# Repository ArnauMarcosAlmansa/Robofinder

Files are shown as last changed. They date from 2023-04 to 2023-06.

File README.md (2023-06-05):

<h1 style="font-size: 48px;">ROBOFINDER</h1>

# Introducción
<p align="justify">
Robofinder es un proyecto de la asignatura de Robótica del Grado en Ingeniería Informática de la Universidad Autónoma de Barcelona.
</p>

<p align="justify">
Este robot ha sido diseñado para la exploración y el mapeo de entornos. Gracias al algorismo de Simultaneous Localization and Mapping (SLAM), RoboFinder tiene la capacidad de generar mapas tridimensionales detallados mientras se mueve con autonomía. Robofinder es un robot móvil autónomo capaz de navegar por un edificio y poder encontrar todo tipo de objetos y localizarse a sí mismo a partir de estos.  Este es un proyecto basado en lo que se conoce como visual SLAM. 
</p>

<div align="center">
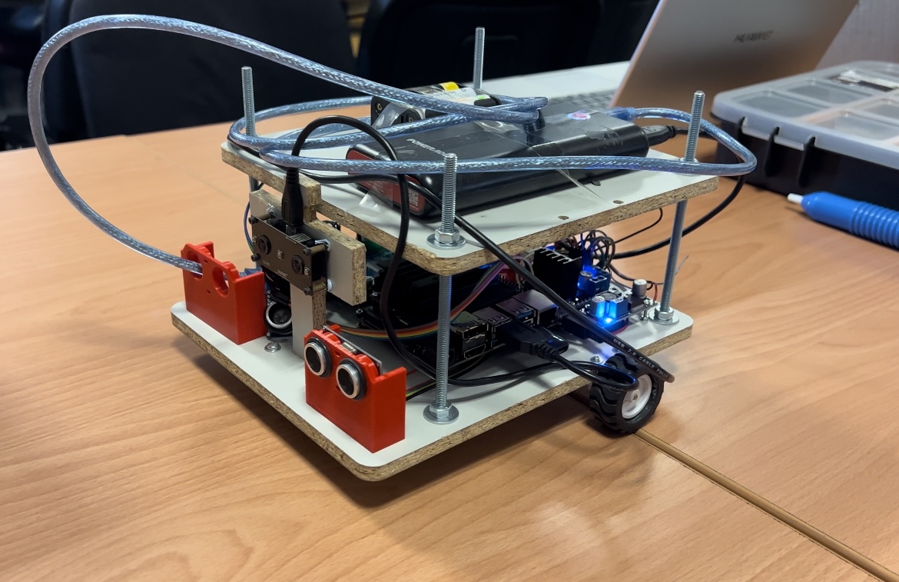
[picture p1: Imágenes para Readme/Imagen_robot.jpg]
Foto
    
</div>

# Tabla de Contenidos
- [Introducción](#introducción)
- [Características](#características)
- [Hardware](#hardware)
    - [Componentes](#componentes)
    - [Circuito](#circuito)
    - [Diseño y Materiales](#diseño-y-materiales)  
- [Software](#software)
- [Resultado Final](#resultado-final)
- [Demo Video](#demo-video)
- [Agradecimientos](#agradecimientos)
- [Autores](#autores)

# Características

<p align="justify">
Su sistema se basa en una cámara estéreo y encoders, permitiéndole obtener una comprensión precisa de su ubicación en todo momento.
</p>

<p align="justify">
RoboFinder cuenta con un potente sistema de control. Una Jetson Nano se encarga del procesamiento, mientras que la comunicación I2C asegura una transmisión de información fluida y confiable entre los componentes. Este enfoque de control inteligente garantiza movimientos precisos y coordinados en cada acción que realiza.
</p>

<p align="justify">
Además de su capacidad de mapeo y navegación, RoboFinder se preocupa por la seguridad. Sus sensores de ultrasonido le permiten detectar obstáculos cercanos y detenerse de manera segura para evitar colisiones. Para brindar una experiencia visualmente atractiva, hemos incorporado LEDs que indican el movimiento del robot, añadiendo un toque estético a su funcionalidad.
</p>

<p align="justify">
Representa un avance significativo en la exploración robótica, abriendo nuevas posibilidades en campos como la cartografía, la inspección de entornos complejos y la investigación científica. Su combinación de tecnología innovadora y capacidad de adaptación lo convierten en una herramienta versátil y confiable.
</p>

<p align="justify">
Descubre con RoboFinder un mundo de posibilidades en la exploración y mapeo de entornos. Siéntete parte de la revolución robótica y únete a nosotros en la búsqueda de soluciones avanzadas para desafíos del mundo real
</p>

# Hardware
## Componentes
Principales componentes utilizados:

 Componente                                  |        Componente                                   |              
|:--------------------------------------------:|:--------------------------------------------:|
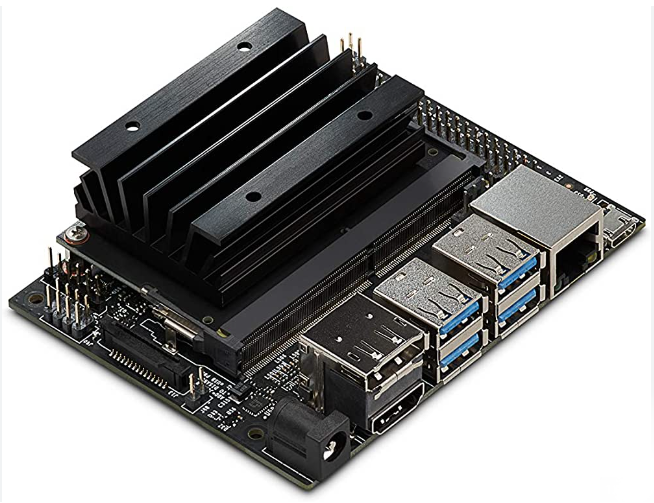
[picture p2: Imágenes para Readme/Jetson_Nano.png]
Jetson Nano
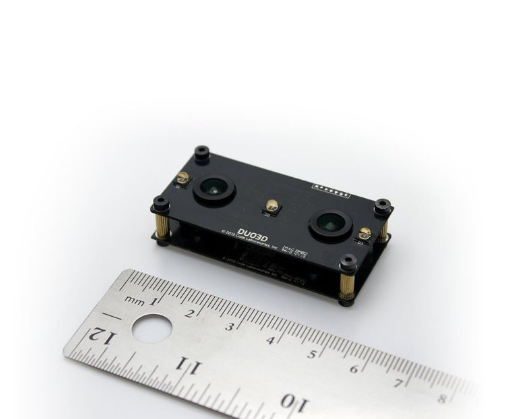
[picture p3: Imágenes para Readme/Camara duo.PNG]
DUO MLX - USB Stereo Camera
| **Nvidia Jetson Nano Developer Kit**  | **DUO MLX - USB Stereo Camera**  |
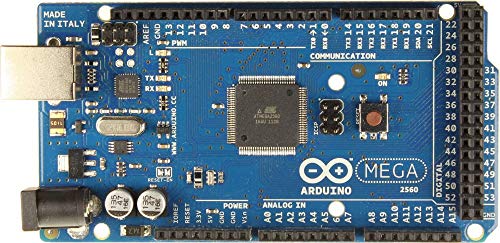
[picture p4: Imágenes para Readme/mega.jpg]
1 Arduino Mega
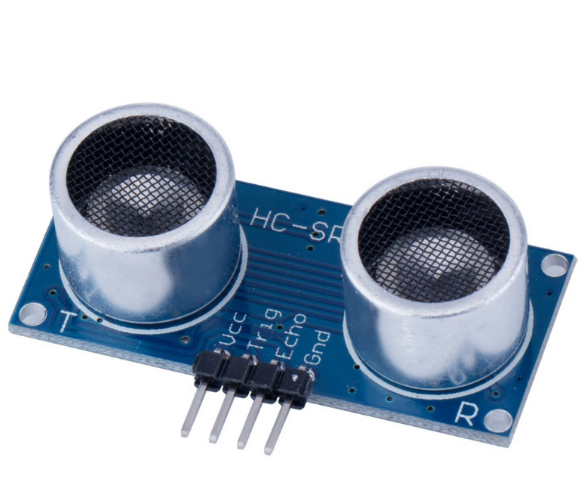
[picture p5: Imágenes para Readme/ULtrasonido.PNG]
2 Sensores de distancia por ultrasonidos HC-SR04
| **1 Arduino Mega**    | **2 Sensores de distancia por ultrasonidos HC-SR04**  |
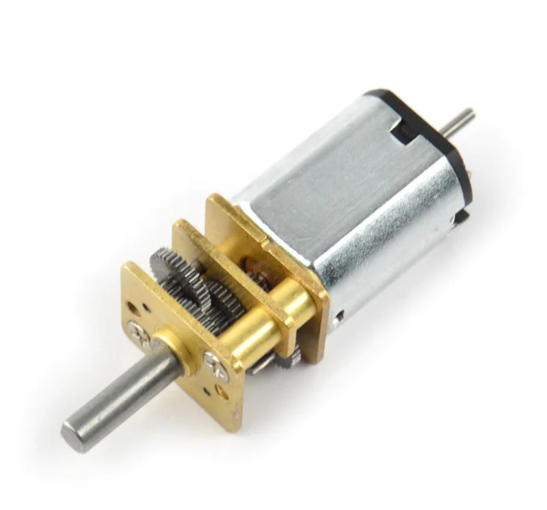
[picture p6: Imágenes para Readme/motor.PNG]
2 Motor Micro Metal 150:1
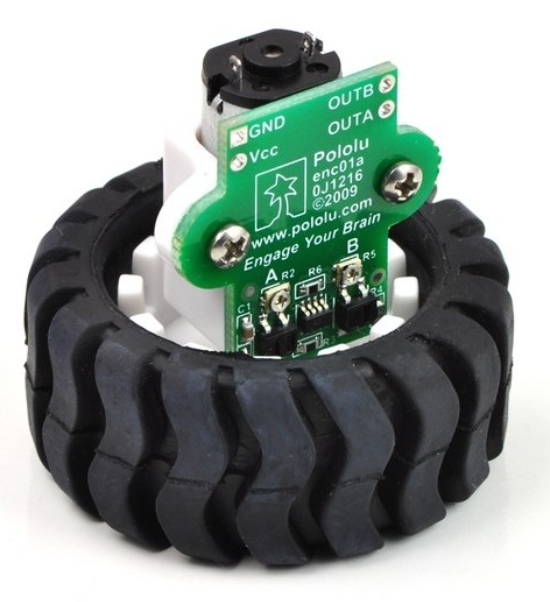
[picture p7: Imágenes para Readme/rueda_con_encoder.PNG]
2 Ruedas antideslizantes con encoders
| **2 Motor	Micro Metal 150:1**  | **2 Ruedas antideslizantes con encoders**                         |
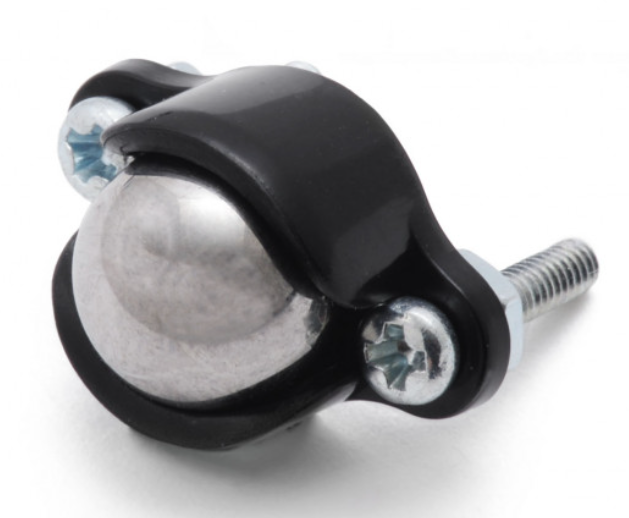
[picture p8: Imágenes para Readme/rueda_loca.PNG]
Rueda loca
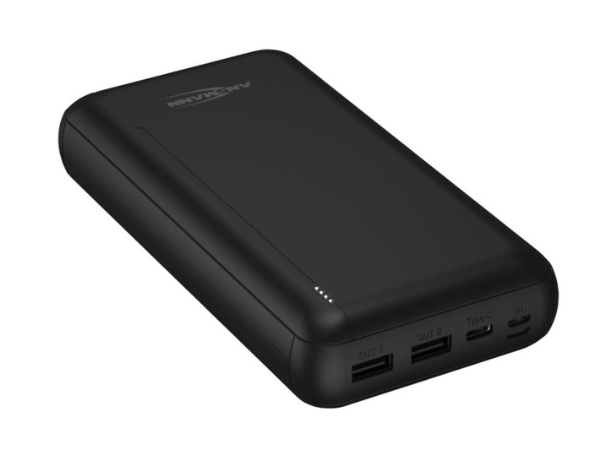
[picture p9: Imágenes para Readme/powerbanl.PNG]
Power Bank 20A
| **1 Rueda Loca Metálica** | **Power Bank 20A** |

## Circuito
Esquema global de Robofinder:

<div align="center">
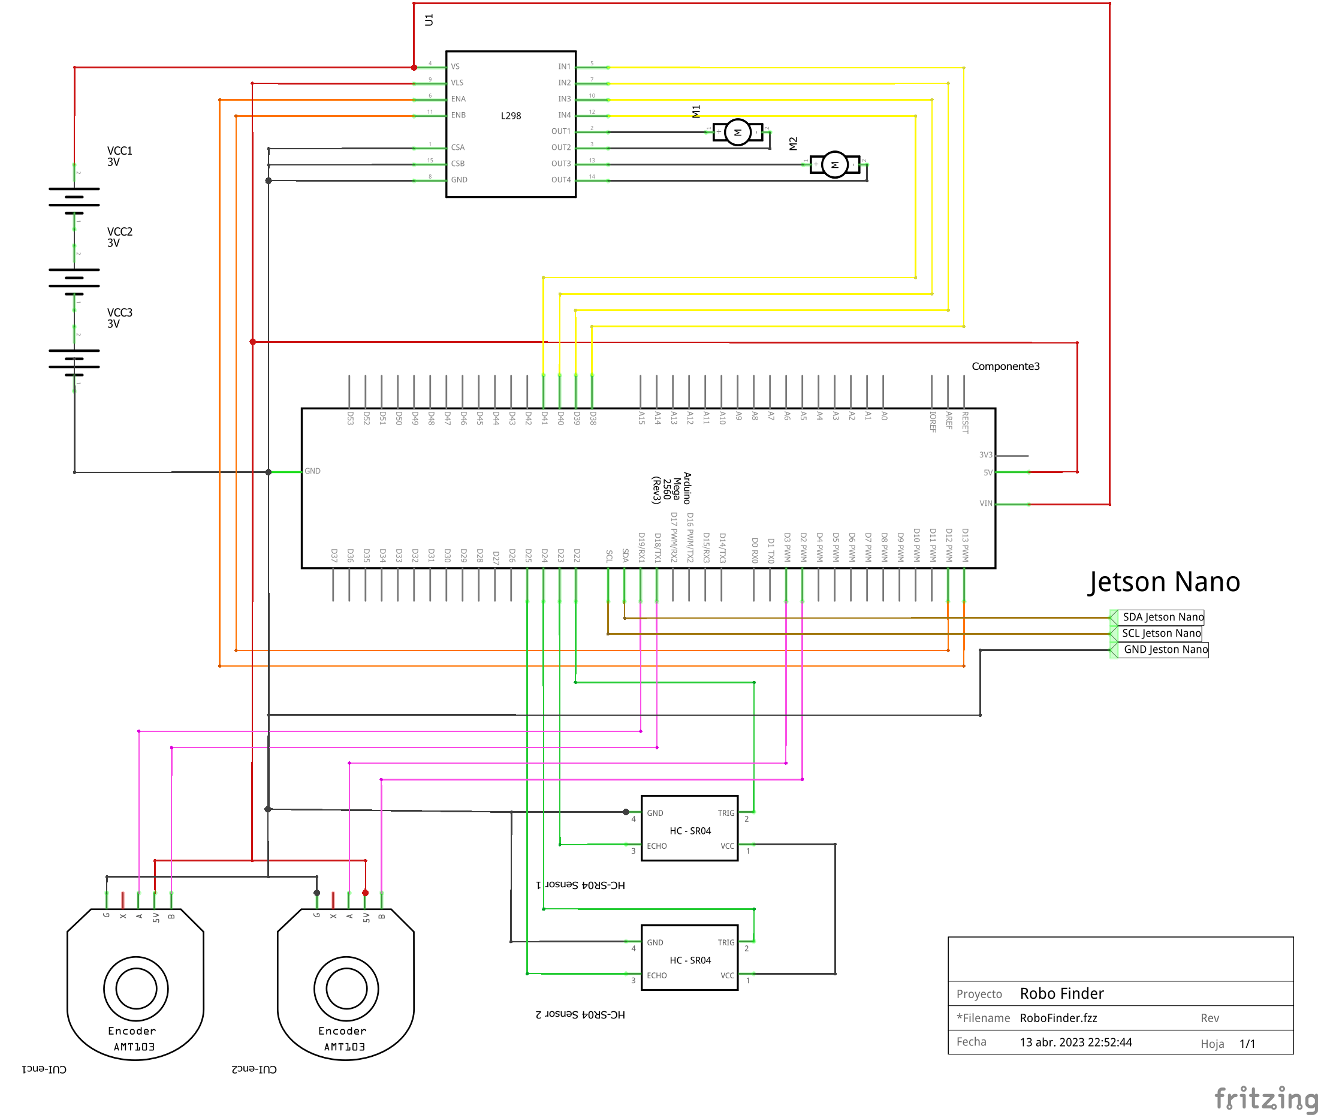
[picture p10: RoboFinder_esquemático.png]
Circuito
    
</div>

<p align="justify">
El Arduino tiene conectado el controlador de motores (L298N), los dos sensores de ultrasonido (HC-R04) y los encoders para detectar el movimiento de los motores.
Aparte el Arduino se comunica con la Jetson Nano mediante I2C. 
En la Jetson Nano tenemos conectada la cámara estéreo (DUO 3D MLX) mediante USB y la conexión de I2C mediante GPIO (puerto 3 SDA , puerto 5 SCL y puerto 6 GND).
</p>

# Diseño y Materiales
Diseño final de la estructura:

 Componente                                  |        Componente                                   |              
|:--------------------------------------------:|:--------------------------------------------:|
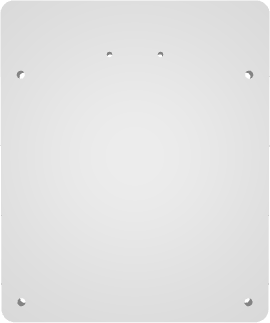
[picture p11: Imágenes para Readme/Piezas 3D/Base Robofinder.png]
Base del Robot
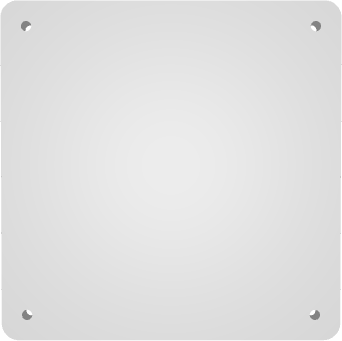
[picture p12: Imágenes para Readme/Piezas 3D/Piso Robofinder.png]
Piso intermedio y superior del Robot
| **Base del Robot**  | **Piso intermedio y superior del Robot** 
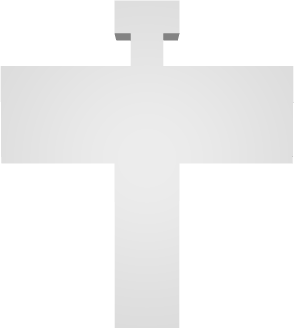
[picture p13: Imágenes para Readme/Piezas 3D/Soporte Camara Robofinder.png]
Soporte de la cámara 3D
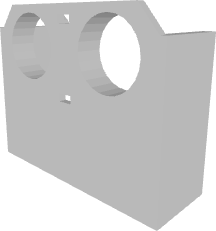
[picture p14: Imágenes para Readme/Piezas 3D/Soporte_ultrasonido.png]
Soporte para los sensores de ultrasonido
| **Soporte de la cámara 3D**  | **Soporte para los sensores de ultrasonido** 
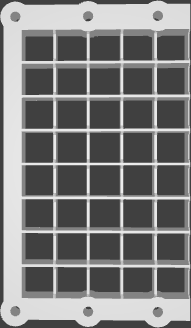
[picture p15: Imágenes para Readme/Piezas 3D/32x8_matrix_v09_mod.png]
Soporte para la matriz led
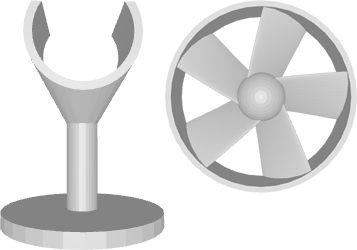
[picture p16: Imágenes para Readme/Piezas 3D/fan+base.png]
Soporte para el motor y aspa
| **Soporte para la matriz led**  | **Soporte para el motor y aspa** 

Si quieres ver el diseño en 3D en detalle, presiona en esta imagen:

<div align="center">
<a href="https://github.com/ArnauMarcosAlmansa/Robofinder/blob/master/models/Piezas_robofinder_montado.stl">
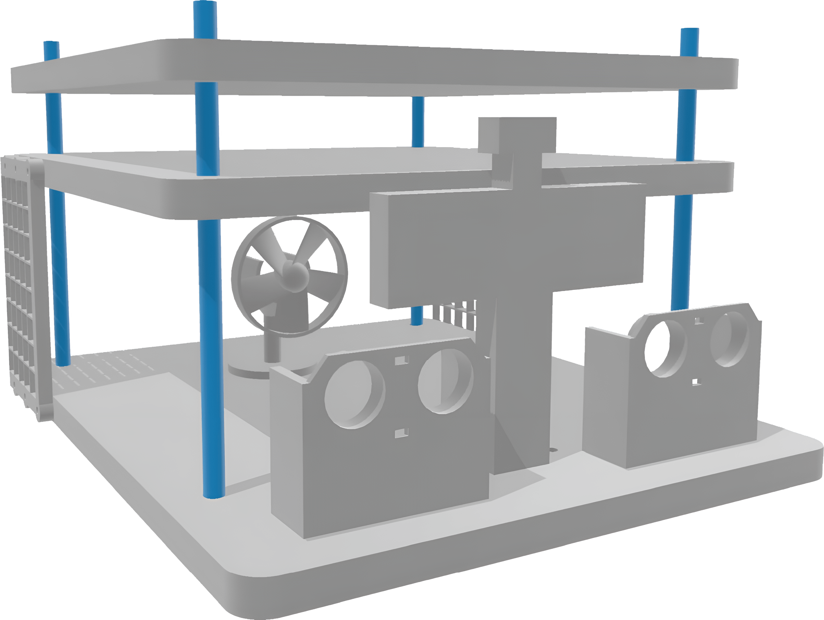
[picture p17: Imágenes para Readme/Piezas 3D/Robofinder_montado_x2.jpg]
  
</a>
</div>

# Software
## Diagrama Software:

<div align="center">
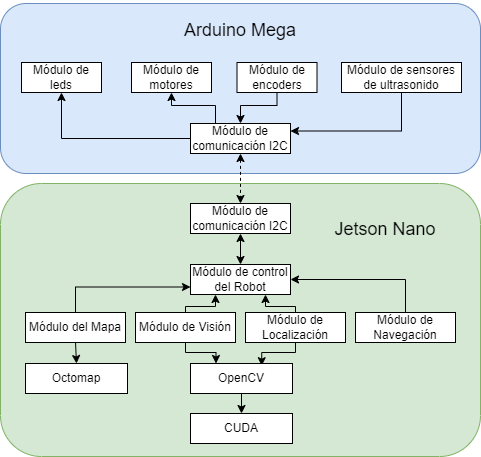
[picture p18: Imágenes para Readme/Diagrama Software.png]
Diagrama Software
    
</div>

## Módulos para el Arduino:

<div align="justify">
    
- **Módulo de control de motores:** Encargado de comandar a los motores: cómo tienen que moverse, velocidad, sentido; y qué motor debe moverse para poder moverse en línea recta o hacer curvas sobre su propio eje o abiertas; también poder frenar por si detecta algún imprevisto.

- **Módulo de sensores encoder:** Para poder leer datos de los encoders, cuantas vueltas dan las ruedas, o cuando completan una vuelta, etc.

- **Módulo de sensores de ultrasonido:** Para poder obtener los valores de los sensores de ultrasonido y poder alertar sobre objetos en la trayectoria.

- **Módulo de comunicación I2C:** Para poder comunicarse con la Jetson Nano. Tanto para recibir como enviar información, respecto a cuando hay que empezar a moverse (sentido, velocidad, posición final) o si hay que pararse. Permite comunicar los sensores de ultrasonido y los encoders con la Jetson para que así esta pueda tener los valores de estos sensores.

- **Módulo de control (interpretar órdenes que da la Jetson, capacidad de responder a imprevistos):** Entender las órdenes que recibimos de la Jeston Nano y poder gestionar las interrupciones que nos pueden dar los sensores de ultrasonido si un objeto inesperado se nos cruza en nuestra trayectoria.

- **Módulo de leds:** Permite definir distintos patrones en la matriz led que tiene el robot. Esta nos notifica cuando el robot se mueve, hacia qué dirección lo hace o si está parado.
    
</div>

## Módulos para la Jetson:

<div align="justify">

- **Módulo de comunicación I2C** Para poder comunicar con el Arduino cuando ha de empezar a mover los motores, qué motores, a que velocidad, también para recibir datos de los sensores de ultrasonido y los valores de los encoders. La comunicación se hace usando un protocolo de mensajes que hemos definido nosotros. Este protocolo envia un byte indicando el tipo de mensaje y un payload de datos.

- **Módulo de Mapa**
Generar un mapa de ocupación 3D del espacio donde se mueve el robot para poder navegar y consultar que tiene el robot a su alrededor y no colisionar con los objetos. Esto nos permite intentar localizar el robot y navegar teniendo en cuenta parte del entorno que el robot no está viendo en un momento concreto.
Hemos hecho uso de la librería OctoMap (https://github.com/OctoMap/octomap).

- **Módulo de Visión**
Este módulo es el encargado de hacer las imágenes con la cámara estéreo. 
Aplicamos el detector de características ORB para encontrar puntos de interés junto con BruteForce Matcher. Hacemos la correspondencia entre los puntos de ambas imágenes y filtramos las correspondencias para quitar las malas. Esto lo hacemos con el ratio de Lowe y filtrando las que tienen coordenada ‘y’ muy diferente. 
Triangulamos los puntos en el espacio 3D de la cámara. Luego los convertimos al espacio 3D del mundo.
Para hacer el procesamiento usamos OpenCV con CUDA.

- **Módulo de Localización**
Este módulo se encarga de intentar ubicar al robot dentro del espacio usando la información del mapa y los puntos que detecta la cámara.
Para conseguir ubicar el robot este módulo incorpora la localización de Monte Carlo para poder determinar en que zona está el robot. 
Concretamente, generamos partículas en un rango probable de error del robot. Para asignar a cada partícula un peso hacemos RayCast desde la posición y orientación de una especie de cámara virtual de cada partícula y hacemos un KNN con k = 1 con los puntos detectados de la cámara, asignando un peso menor a aquellas partículas que tienen menor correspondencia con los puntos de la cámara.
Después de esto, hacemos un resampling de partículas con el algoritmo llamado Random Wheel, que consiste en  generar nuevas partidas a partir del peso cumulativo de las anteriores.
Todo el proceso anterior se itera cinco veces para refinar y aproximar la posición estimada del robot.
Para este módulo utilizamos la parte de ML de OpenCV.

- **Módulo de Navegación**
Este módulo se encarga de planificar la navegación local.
Este módulo es el que se encarga de generar las órdenes que finalmente llegan al Arduino para la gestión de los motores y de los sensores. 
Teniendo en cuenta la posición del robot, hacemos raycast 360 grados alrededor del robot a 15 alturas diferentes de 0.5 cm a 15.5 cm, que es la altura del robot. A partir de los datos del raycast, el robot busca un ángulo donde no haya obstáculos, mira que no haya obstáculos con los ultrasonidos y avanza.

</div>

# Resultado Final

# Demo Video
Presiona la miniatura para visualizar el video en youtube de todo el proceso!

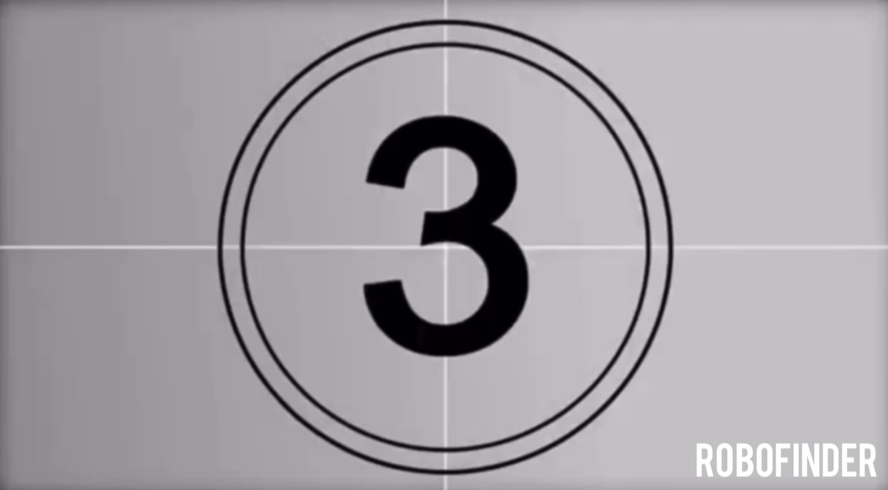
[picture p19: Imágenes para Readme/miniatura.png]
Demo del proyecto (https://youtu.be/TqlxrmKnXCs/)


# Agradecimientos
<p align="justify">
Queremos destacar y agradecer especialmente a la UAB, junto a los profesores de esta asignatura por proporcionarnos los mejores componentes posibles y por el apoyo brindado semanalmente.
</p>

[Universitat Autònoma de Barcelona (UAB)](https://www.uab.cat/web/universitat-autonoma-de-barcelona-1345467954409.html)

<p align="justify">
También al equipo del Open lab por facilitarnos la impresión 3D, el material y todas las herramientas que nos han permitido llevar a cabo nuestro robot.
</p>

[Open Labs UAB](https://www.uab.cat/open-labs/)

# Autores
- [Pere Pérez López](https://github.com/Pachi23)

- [Lluís Alonso Pichardo](https://github.com/lluisalosnsop)

- [Arnau Marcos Almansa](https://github.com/ArnauMarcosAlmansa)

- [Sergi Sanz Orellana](https://github.com/sergisanzorellana)

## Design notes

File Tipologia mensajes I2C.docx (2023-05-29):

# Arduino:

Tiene:

- Controladora de Motores
- Encoders
- Sensor ultrasonido

Recibe:

- Órdenes controladora de motores

Envía:

- Medida sensores ultrasonido
- Datos Enconders.

Con 2Bytes para los mensajes.

0 - 255 | 0 - 255
Canal | Valor

## Canales

### Motores:

10 -> Enable Motors (Sin mensaje 0Bytes)

11 -> Forward (Velocidad motor L (1Byte), Velocidad motor R (1Byte), Valor final encoder (2Bytes))

12 -> Backward (Velocidad motor L (1Byte), Velocidad motor R (1Byte), Valor final encoder (2Bytes))

13 -> Left (Velocidad motor L (1Byte), Velocidad motor R (1Byte), Valor final encoder (2Bytes))

14 -> Right (Velocidad motor L (1Byte), Velocidad motor R (1Byte), Valor final encoder (2Bytes))

15 -> Stop (Sin mensaje 0Bytes)

### Encoder:

20 -> Encoder Left (Sin mensaje 0Bytes)

21 -> Encoder Right (Sin mensaje 0Bytes)

22-> Reset Encoder Left (Sin mensaje 0Bytes)

23-> Reset Encoder Right (Sin mensaje 0Bytes)

### Ultrasound:

31 -> Ultrasound Left (Sin mensaje 0Bytes)

32 -> Ultrasound Right (Sin mensaje 0Bytes)

### LED:

40 -> Led Off (Sin mensaje 0Bytes)

Canales primera propuesta:

Controladora Motor Izquierda.

Característica | Canal | Rango de Valor
Velocidad | 10 | 1-255
Sentido | 11 | 1 -> Forward; 2 -> Backward.
Stop | 12 | 1
Aceleración | 13 | 1-255 (0 no tiene sentido)
Deceleración | 14 | 1-255 (0 no tiene sentido)

Controladora Motor derecha

Característica | Canal | Rango de Valor
Velocidad | 20 | 1-255
Sentido | 21 | 1 -> Forward; 2 -> Backward.
Stop | 22 | 1
Aceleración | 23 | 1-255 (0 no tiene sentido)
Deceleración | 24 | 1-255 (0 no tiene sentido)

Encoder Rueda Izquierda Petición | 30
Respuesta | 31

Encoder Rueda Derecha petición | 40
Respuesta | 41

Sensor Ultrasonido Izquierda | 50
Interrupción del sensor Izquierdo | 51

Sensor Ultrasonido Derecha | 60
Interrupción del sensor derecha | 61

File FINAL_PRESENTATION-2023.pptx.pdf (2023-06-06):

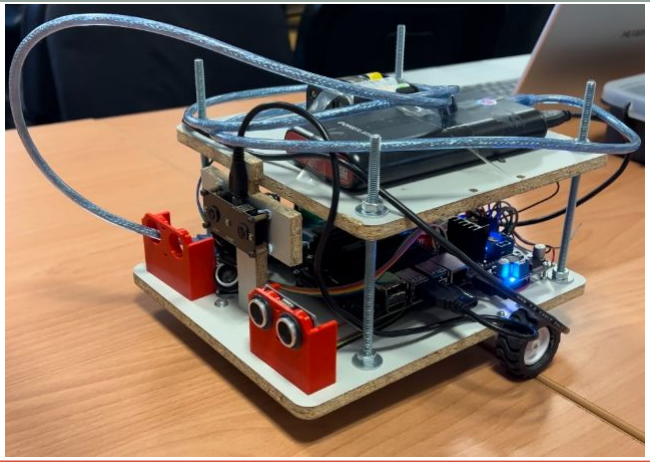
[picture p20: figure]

# ROBOFINDER

Arnau Marcos Almansa Pere Pérez López Lluís Alonso Pichardo | Robofinder es un robot móvil autónomo capaz de navegar por un edificio, detectar puntos en el entorno y localizarse a sí mismo a partir de estos. Este es un proyecto basado en lo que se conoce como visual SLAM.
| Sergi Sanz Orellana

ROBÒTICA, LLENGUATGE I PLANIFICACIÓ – ENGINYERIA INFORMÀTICA - UAB

# 1. Arquitectura hardware i software

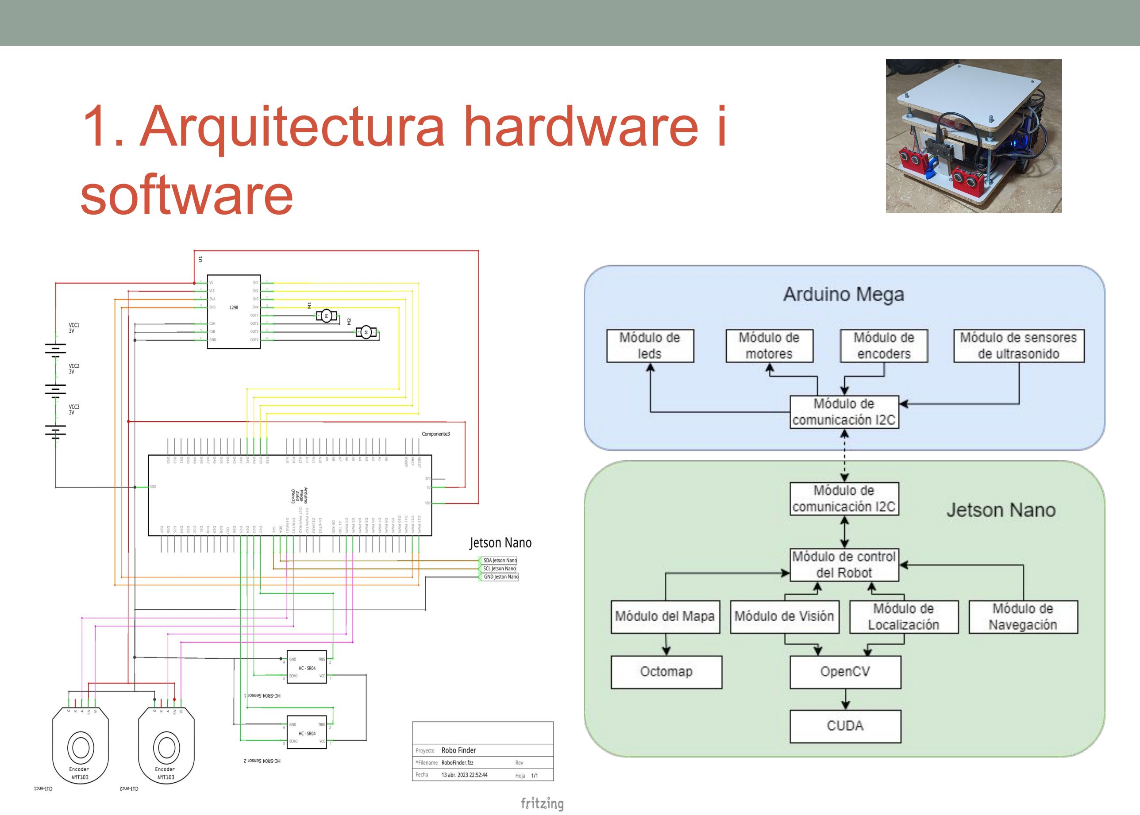
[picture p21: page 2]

# 2. Algorísmica

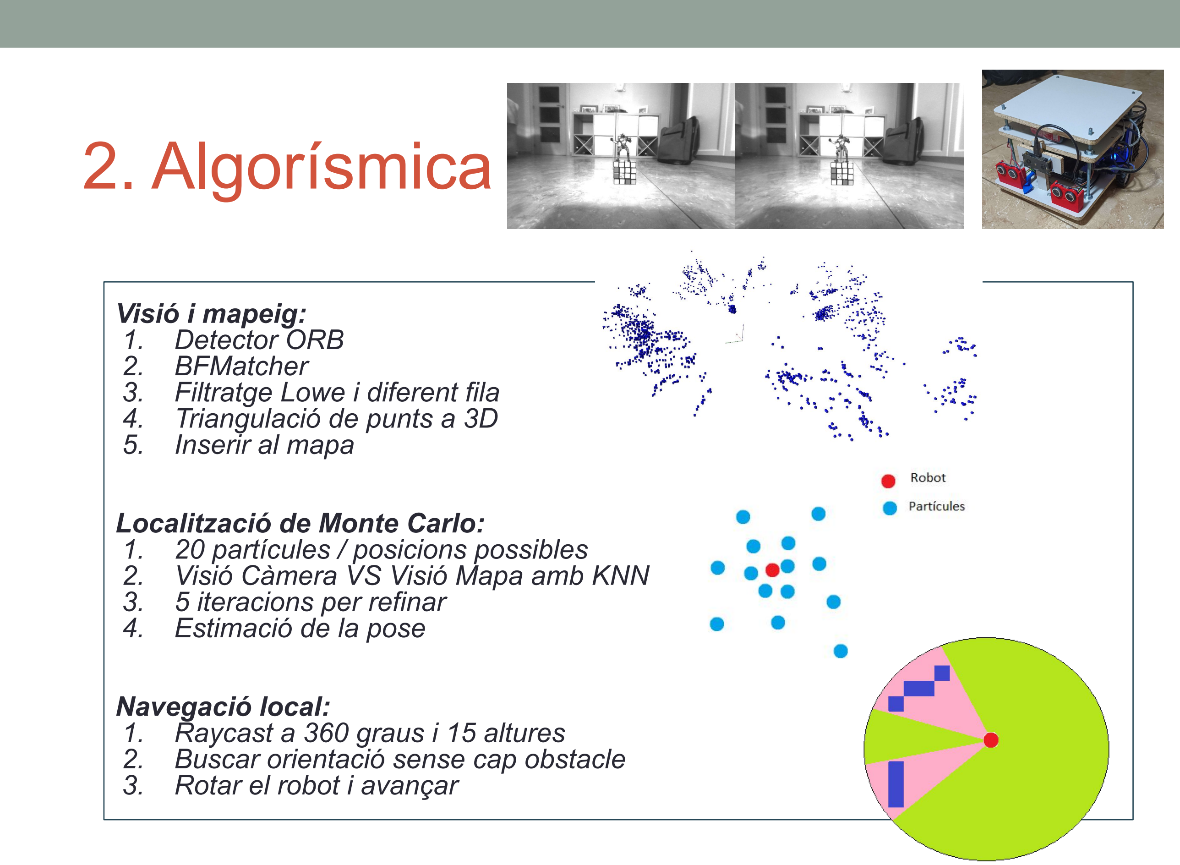
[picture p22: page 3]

Visió i mapeig:
1. Detector ORB
2. BFMatcher
3. Filtratge Lowe i diferent fila
4. Triangulació de punts a 3D
5. Inserir al mapa

Localització de Monte Carlo:
1. 20 partícules / posicions possibles
2. Visió Càmera VS Visió Mapa amb KNN
3. 5 iteracions per refinar
4. Estimació de la pose

Navegació local:
1. Raycast a 360 graus i 15 altures
2. Buscar orientació sense cap obstacle
3. Rotar el robot i avançar

# FOTOS, VIDEO i Git

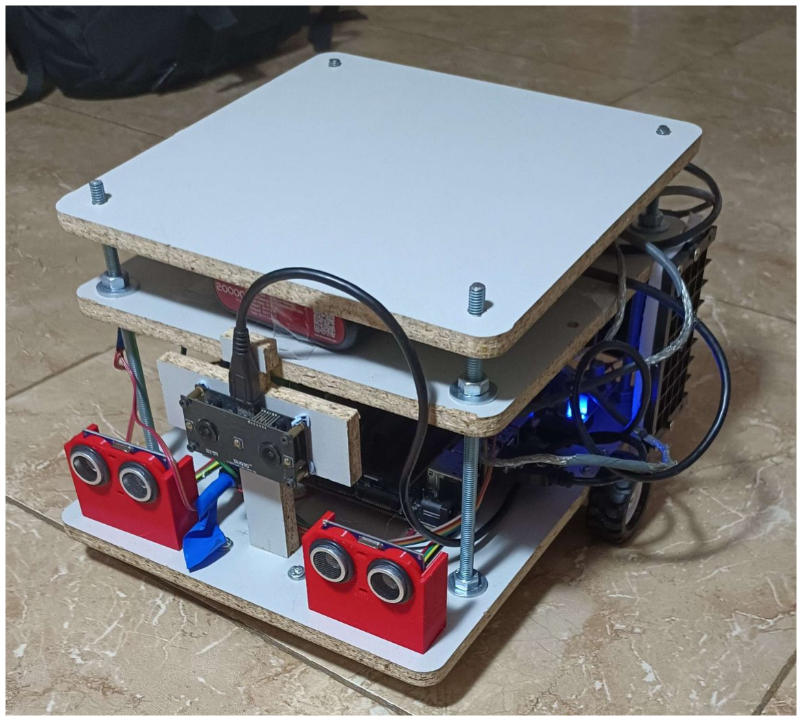
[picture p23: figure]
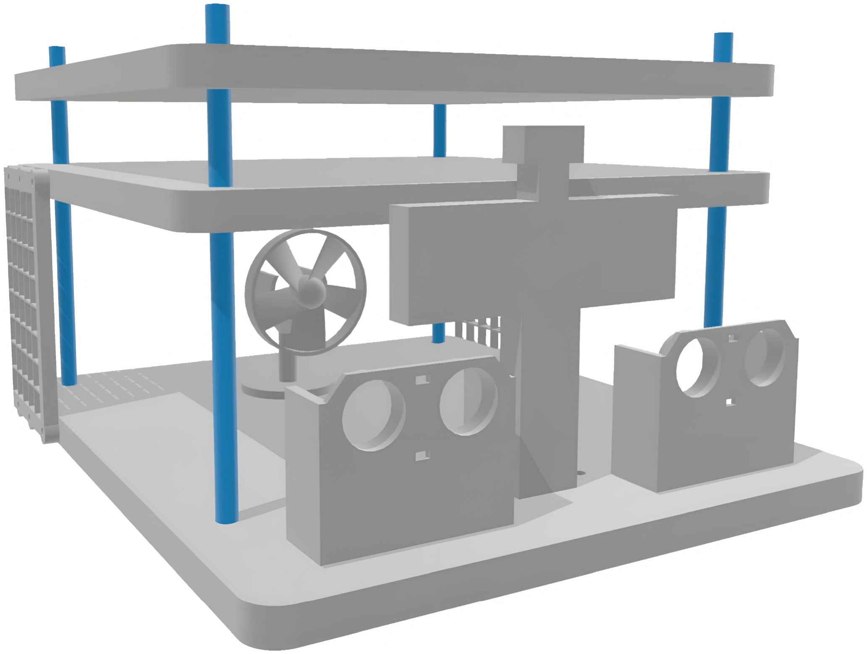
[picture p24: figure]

# https://youtu.be/TqlxrmKnXCs

https://github.com/ArnauMarcosAlmansa/Robofinder

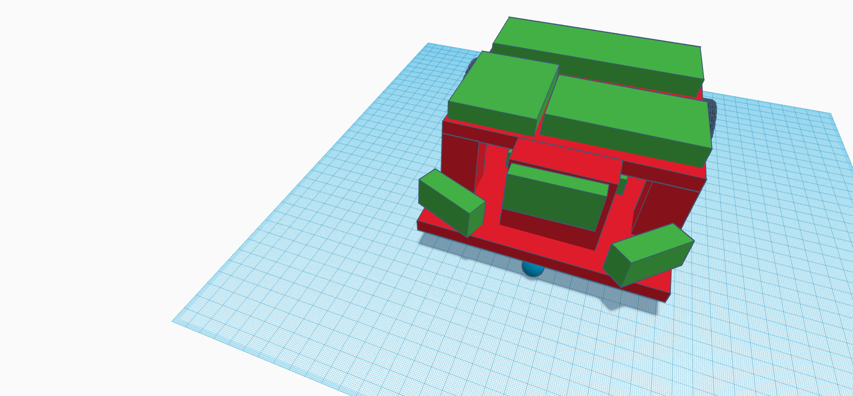
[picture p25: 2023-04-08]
ROBOT DESIGN.png

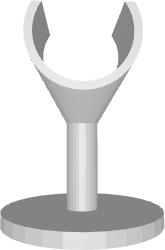
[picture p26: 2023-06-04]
Imágenes para Readme/Piezas 3D/fan_base.png

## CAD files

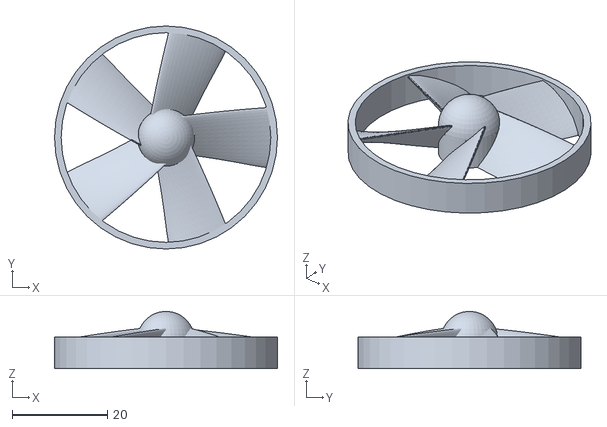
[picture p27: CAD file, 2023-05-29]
models/Fan/fan.stl
46.8 x 46.8 x 12.0

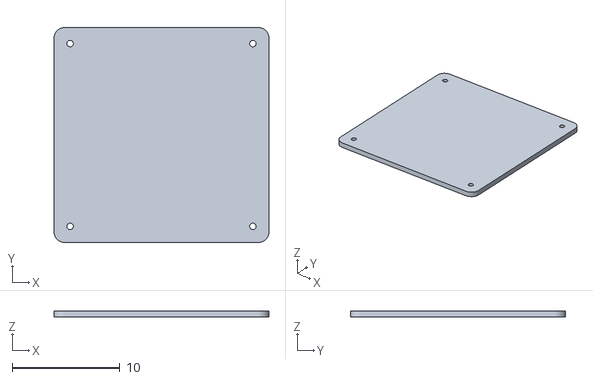
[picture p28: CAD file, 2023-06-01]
models/Fresadora/Piso Robofinder.stl
20.0 x 20.0 x 0.6

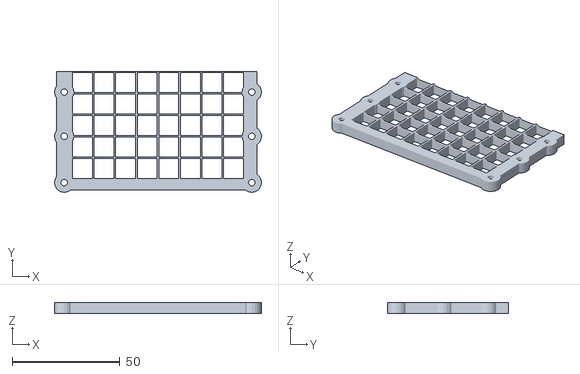
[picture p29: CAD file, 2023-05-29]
models/Matriz led/32x8_matrix_v09_mod.stl
96.0 x 56.0 x 5.00

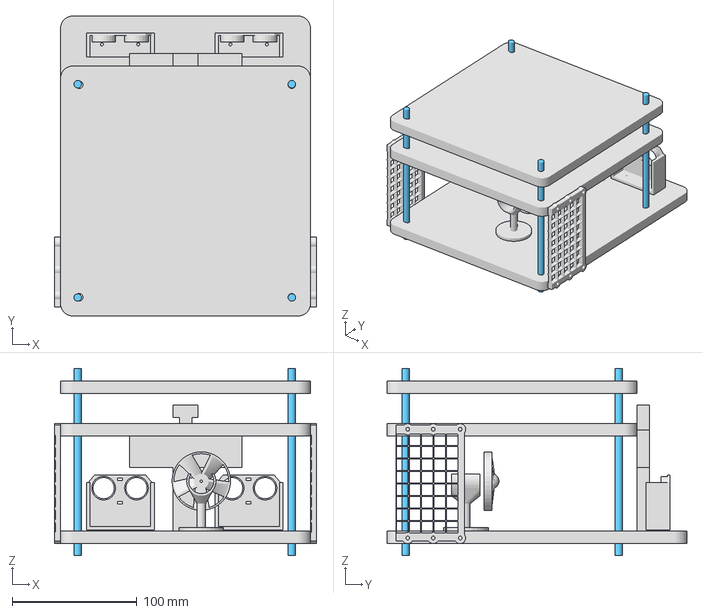
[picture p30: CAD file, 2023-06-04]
models/Piezas_robofinder_montado.3mf
210.0 x 240.0 x 150.0 mm

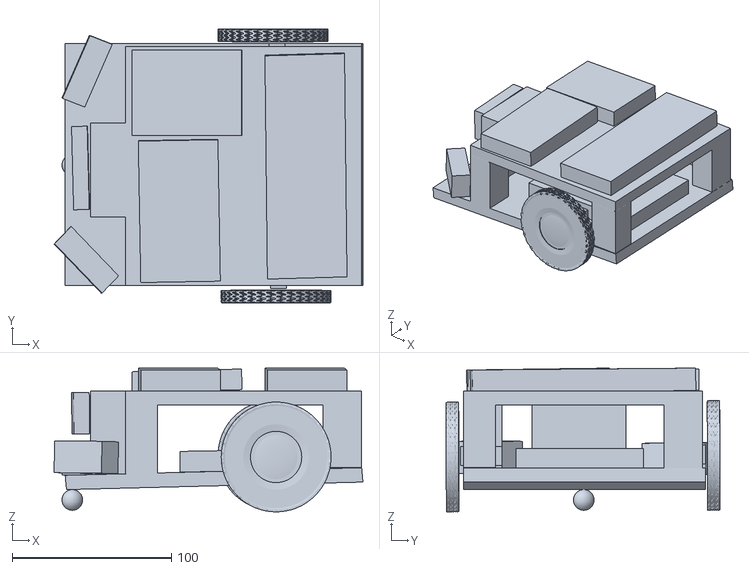
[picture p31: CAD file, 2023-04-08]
ROBOT DESIGN.stl
194.1 x 172.0 x 90.3

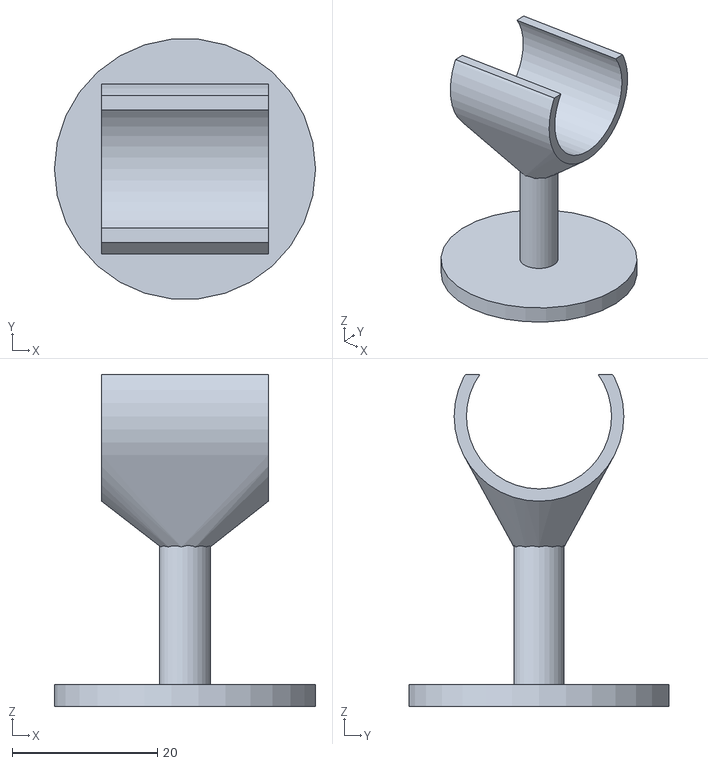
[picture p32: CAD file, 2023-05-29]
models/Fan/fan_base.stl
36.0 x 35.8 x 45.8

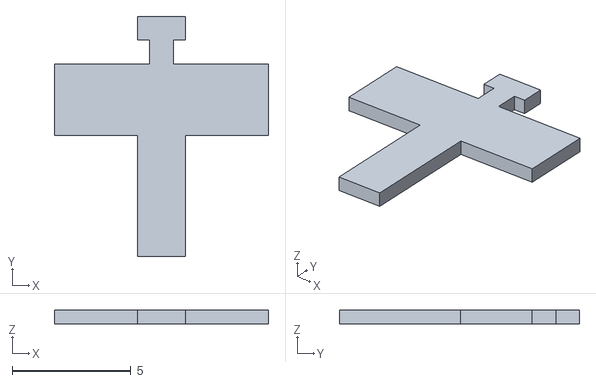
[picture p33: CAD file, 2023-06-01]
models/Fresadora/Soporte Camara Robofinder.stl
9.00 x 10.1 x 0.6

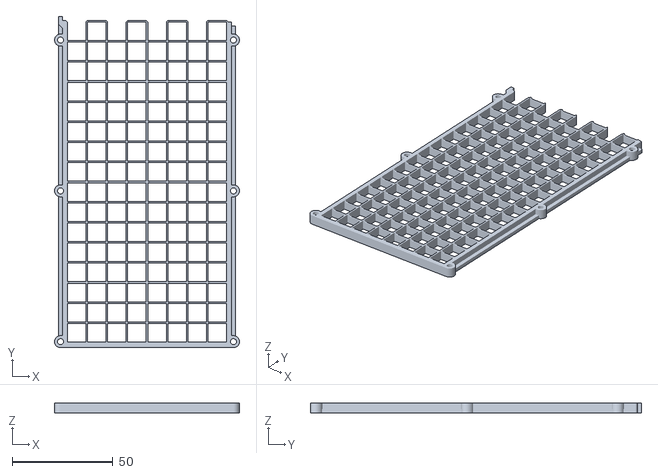
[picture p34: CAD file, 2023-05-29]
models/Matriz led/32x8_matrix_v09.stl
92.0 x 164.8 x 5.00

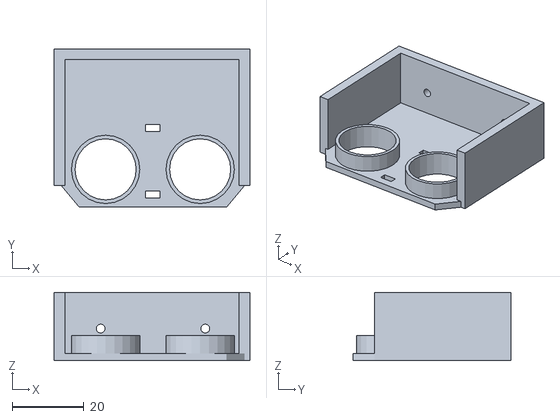
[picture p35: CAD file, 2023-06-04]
models/soporte_ultrasonido.stl
54.5 x 44.0 x 19.0

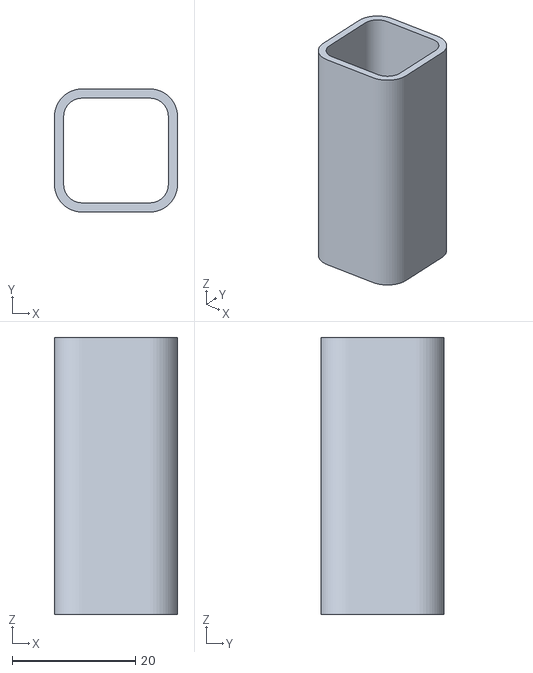
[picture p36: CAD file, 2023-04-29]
models/column.stl
20.0 x 20.0 x 45.0

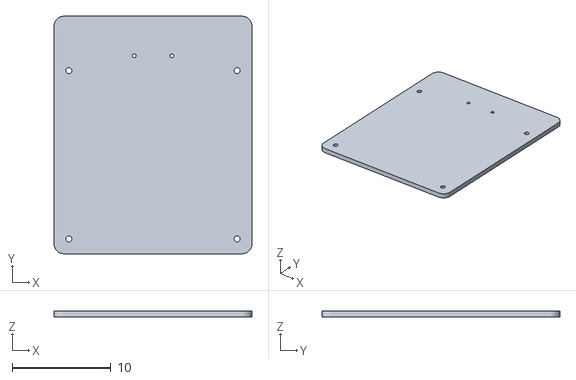
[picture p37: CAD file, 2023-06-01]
models/Fresadora/Base Robofinder.stl
20.0 x 24.0 x 0.6

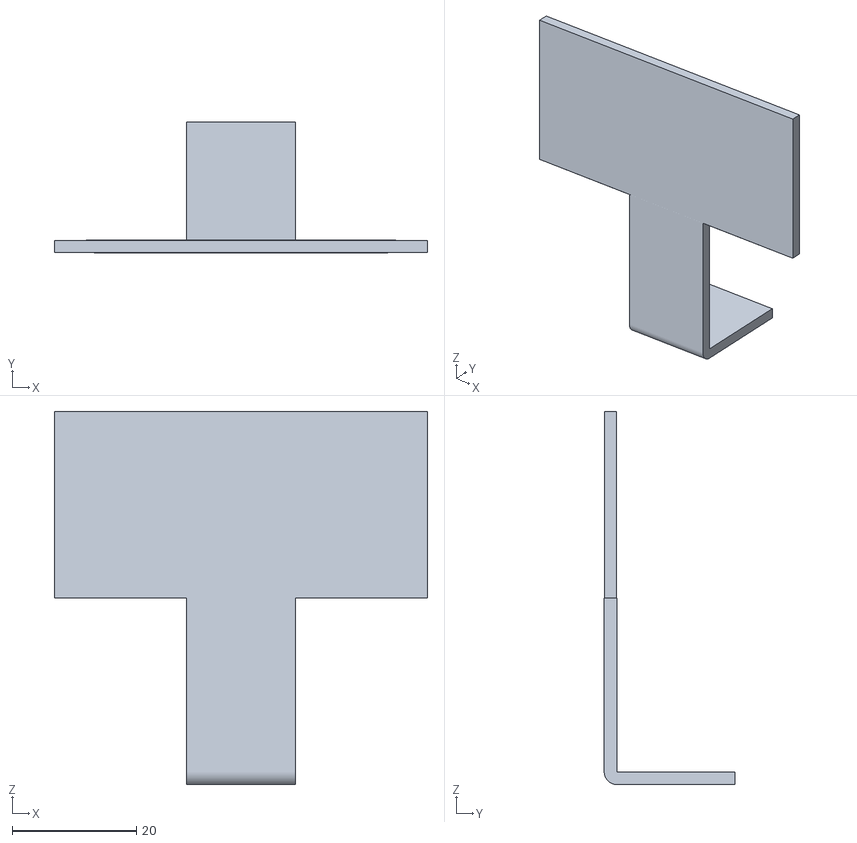
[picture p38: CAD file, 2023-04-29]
models/camera_support.stl
60.0 x 21.0 x 60.0

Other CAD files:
models/Fresadora/Base Robofinder.dxf
models/Fresadora/Piso Robofinder.dxf
models/Fresadora/Soporte Camara Robofinder.dxf
models/Piezas_robofinder_montado.stl
models/robot.blend

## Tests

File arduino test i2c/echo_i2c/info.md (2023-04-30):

# Ver dispositivos I2C y sus direcciones.
sudo i2cdetect -y 1

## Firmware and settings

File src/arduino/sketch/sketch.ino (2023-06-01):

#include "Encoder.h"
#include "Motor.h"
#include "UltrasoundSensor.h"
#include "led.h"
#include <Wire.h>
#include <string.h>
#include <stdio.h>
#include <stdlib.h>


Encoder encoderLeft(19,18);
Encoder encoderRight(3,2);

UltrasoundSensor ultrasoundsensorLeft(24, 25);
UltrasoundSensor ultrasoundsensorRight(22, 23);

Motor motorLeft(13, 38, 39);
Motor motorRight(12, 40, 41);

Led led(6, 256);  // Configurar el objeto Led con el pin y el número de LEDs


int encoder_left_final_position = 0;
int encoder_right_final_position = 0;

// bool send_pending = false;

int bytes_messages_i2c[40] = {
  0,
  0,
  0,
  0,
  0,
  0,
  0,
  0,
  0,
  0,
  0,
  4,
  4,
  4,
  4,
  0,
  0,
  0,
  0,
  0,
  0,
  0,
  0,
  0,
  0,
  0,
  0,
  0,
  0,
  0,
  0,
  0,
  0,
  0,
  0,
  0,
  0
  }; // Numero de Bytes que tendran los mensajes por canal (Numero -1). El canal es el indice de la lista.

#include "i2c.h"


bool i2c_interrupt = false;             // Hacemos la condicion dentro del loop al tener el mensaje completo
int channel_received_i2c = 0;           // El canal que especifica el usuario que quiere usar. (Es el primer mensaje de 1Byte que recibimos).

int response_count = 0;                 // Temporal. Numero de mensajes enviados a la Jetson.
int repsonse_channel = 0;               // Canal con el enviamos los mensajes a la Jetson.
int response_i2c = 0;                   // Valor que devolvemos por I2C a la Jetson.

int message_count = 0;                  // Temporal. Cuenta los mensajes que hemos recibido.
int total_number_message = 0;           // Temporal. Guardamos el numero total de mensajes que tienen que llegar para el canal seleccionado.
uint8_t message_i2c[4] = {0,0,0,0};     // Mensajes de recibimos de 1Bytes cada uno.

int count_loop = 0;                     // Contador de iteraciones en el loop. Para realizar la medicion de los ultrasonidos.
int ultrasonic_limit = 10;              // Limite de distancia en el que los ultrasonidos pararan el movimineto del robot.


void updateEncoders() {
  encoderRight.update();
  encoderLeft.update();


// Comprobamos si el motor ha llegado a la posicion que queremos.
  if (abs(encoderRight.read()) >= abs(encoder_right_final_position)) {
    motorRight.stop(); // Paramos el motor
    /*Serial.print("Encoder Right");
    Serial.println(encoderRight.read());
*/
    /*response_i2c = abs(encoder_right_final_position);
    response_count = 0;
    i2c_sendData();*/
    encoder_right_final_position = 0; // Reiniciamos la variable con un valor no valido.
    //led.off();
    //led.ide();
  }


  // Comprobamos si el motor ha llegado a la posicion que queremos.
  if (abs(encoderLeft.read()) >= abs(encoder_left_final_position)) {
    motorLeft.stop(); // Paramos el motor
    //response_i2c = encoder_left_final_position;
    encoder_left_final_position = 0; // Reiniciamos la variable con un valor no valido.
    //led.off();
    //led.ide();
  }

  
}

void updateEncoderLeft() {
  encoderLeft.update();

  // Serial.print("ENCODER LEFT VALUE: ");
  // Serial.println(abs(encoderLeft.read()));
  // Serial.print("ENCODER LEFT FINAL: ");
  // Serial.println(abs(encoder_left_final_position));
  // Serial.print("UPDATE LEFT #");
  // Serial.println(encoderLeft.updates);

  // Comprobamos si el motor ha llegado a la posicion que queremos.
  if (abs(encoderLeft.read()) >= abs(encoder_left_final_position)) {
    motorLeft.stop(); // Paramos el motor
    encoder_left_final_position = 0; // Reiniciamos la variable con un valor no valido.
    //led.off();
    //led.ide();
  }
}

void updateEncoderRight() {
  encoderRight.update();

  // Serial.print("ENCODER RIGHT VALUE: ");
  // Serial.println(abs(encoderRight.read()));
  // Serial.print("ENCODER RIGHT FINAL: ");
  // Serial.println(abs(encoder_right_final_position));
  // Serial.print("UPDATE RIGHT #");
  // Serial.println(encoderRight.updates);


  // Comprobamos si el motor ha llegado a la posicion que queremos.
  if (abs(encoderRight.read()) >= abs(encoder_right_final_position)) {
    motorRight.stop(); // Paramos el motor
    response_i2c = encoder_right_final_position;
    encoder_right_final_position = 0; // Reiniciamos la variable con un valor no valido.
    //led.off();
    //led.ide();
  }
}

void i2c_interrupcion() {
  // Serial.println("i2c_interrupcion START");
  // Serial.print("AVAILABLE BEGINNING: ");
  // Serial.println(Wire.available());
  // Comprobamos si tenemos un canal guardado. Sino tenemos ninguno, el mensaje sera el canal.

  channel_received_i2c = Wire.read();                                 // Leemos el valor y lo guardamos.
  total_number_message = bytes_messages_i2c[channel_received_i2c];    // Miramos el numero de bytes de los mensajes que tendremos para el canal recibido.
  
  message_count = 0;
  while (message_count < total_number_message) {
    message_i2c[message_count] = Wire.read();
    message_count++;   
  }

  response_i2c = I2C().i2cInteruptions(channel_received_i2c, message_i2c);
  repsonse_channel = channel_received_i2c;

  for (int i=0; i<= 4; i++) {
    message_i2c[i] = 0;
  }
  
  total_number_message = 0;
  message_count = 0;

  //  send_pending = true;
  // Serial.print("AVAILABLE END: ");
  // Serial.println(Wire.available());
  // Serial.println("i2c_interrupcion END");
}

void i2c_sendData() { 
  // Serial.println("Send Data");
/*
  Wire.write(repsonse_channel);

  byte byte1 = response_i2c & 0xFF; // obtiene los 8 bits menos significativos
  Wire.write(byte1);
  
  byte byte2 = (response_i2c >> 8) & 0xFF; // desplaza 8 bits hacia la derecha y obtiene los siguientes 8 bits
  Wire.write(byte2);
*/
//  Wire.beginTransmission(0x30);
/*

  byte byte1 = response_i2c & 0xFF; // obtiene los 8 bits menos significativos
  byte byte2 = (response_i2c >> 8) & 0xFF; // desplaza 8 bits hacia la derecha y obtiene los siguientes 8 bits
  
  byte msg[3];
  msg[0] = repsonse_channel;
  msg[1] = byte1;
  msg[2] = byte2;

  Serial.println(msg[0]);
  Serial.println(msg[1]);
  Serial.println(msg[2]);


  Wire.write(msg, 3);
*/
  //Wire.endTransmission(0x30);

  if (response_count == 0) {
     Wire.write(repsonse_channel);
     response_count = 1;
  } else if (response_count == 1) {

    //Serial.println(response_i2c);

    byte byte1 = response_i2c & 0xFF; // obtiene los 8 bits menos significativos
    Wire.write(byte1);
    response_count = 2;
  } else if (response_count == 2) {
    byte byte2 = (response_i2c >> 8) & 0xFF; // desplaza 8 bits hacia la derecha y obtiene los siguientes 8 bits
    Wire.write(byte2);
    response_count = 0;
  }


}

void setup() {
  // put your setup code here, to run once:
  // Serial.begin(9600);
  // Serial.println("BEGIN");

  
  attachInterrupt(digitalPinToInterrupt(2), updateEncoders, CHANGE);
  attachInterrupt(digitalPinToInterrupt(3), updateEncoders, CHANGE);

  attachInterrupt(digitalPinToInterrupt(18), updateEncoders, CHANGE);
  attachInterrupt(digitalPinToInterrupt(19), updateEncoders, CHANGE);

  //attachInterrupt(digitalPinToInterrupt(SDA), i2c_interrupcion, RISING); // Seria para un arduino master no esclavo.
  Wire.begin(0x30);
  Wire.onReceive(i2c_interrupcion);
  Wire.onRequest(i2c_sendData);

  led.begin();  // Iniciar los LEDs NeoPixel
  led.startup();
}

void loop() {

  if ((encoder_left_final_position != 0) || (encoder_right_final_position != 0))
    updateEncoders();
  

  /*
 
  if (send_pending){
    i2c_sendData();
    response_i2c = 0;
    send_pending = false;
  }
  
  */

  // // Serial.println("LOOP START");
  // delay(1000);
  // // Serial.println("LOOP END");
  
  /*
  led.stop();  // Mostrar color rojo
  delay(2000);
  
  led.forward();  // Mostrar color verde
  delay(2000);

  led.backward();
  delay(2000);

  led.ide();
*/
  //delay(2000);
  //delay(2000);*/
  /*
  led.arrowLeft();
  led.arrowRight();
*/  
  //led.ide();

  /*

  if (count_loop > 50){

    if ((ultrasoundsensorLeft.ping_blocking() <= ultrasonic_limit) || (ultrasoundsensorRight.ping_blocking() <= ultrasonic_limit)) { // Comprobamos si hemos llegado a una distancia limite.
      motorLeft.stop();
      motorRight.stop();
      led.stop();
    }

    count_loop = 0;
  }

  count_loop += 1;
  */
}

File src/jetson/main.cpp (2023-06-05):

#include "Robot.h"
#include "vision/Vision.h"
#include "i2c/I2C.h"
#include "map/Map.h"
#include <iostream>
#include <chrono>
#include <utility>
#include <thread>
#include "navegacion/navegacion.h"
#include "localization/Localization.h"
#include <cmath>
using namespace std::chrono_literals;


const double WHEEL_CIRCUMFERENCE = 0.132;
const double pi = 3.14159265359;
const int LIMIT_ULTRASENSOR = 18;


struct CameraParams cam_params;

void doComputeStart(Robot* robot, Map* map, Vision* vision){
    for (int prec = 0; prec < 2; prec++){
	std::cout <<"Trying Start Compute " << std::endl;
    	cv::Mat camera_points = (*vision).detect_points();
    	std::vector<cv::Point3f> cam_points = camera_points;
    	std::vector<cv::Point3f> good_points = (*vision).filter_out_faraway_points(cam_points);
    	std::vector<cv::Point3f> points = (*vision).camera_points_to_world(good_points, (*robot).compute_own_camera_position(), (*robot).get_orientation());
    	map->InsertPointsInTree(points);
        map->SaveMapToFile("mapa");
    }

};

void doRecognition(Robot* robot, Map* map, Vision* vision, Navegacion* nav){
	for (int i = 0; i < 3; i++){
        	doComputeStart(robot, map, vision);
        	int pulsos = (*nav).turn_right90();
        	(*robot).turn_from_last_known_with_pulses(false, pulsos);
        	(*robot).commit();
    	}
	doComputeStart(robot, map, vision);
   	int pulsos135 = (*nav).turn_right135();
	(*robot).turn_from_last_known_with_pulses(false, pulsos135);
	(*robot).commit();
	for (int i = 0; i < 3; i++){
        	doComputeStart(robot, map, vision);
        	int pulsos = (*nav).turn_right90();
        	(*robot).turn_from_last_known_with_pulses(false, pulsos);
        	(*robot).commit();
    	}
}

int findMiddleZeroIndex(std::vector<std::pair<bool, octomap::point3d>>& points) {

    int initial_size = points.size();
    for (int i = 0; i < initial_size; i++)
        points.push_back(points[i]);


    int maxConsecutiveZeros = 0;  // Contador para el número máximo de ceros consecutivos
    int maxConsecutiveZerosIndex = -1;  // Índice del inicio del tramo más largo de ceros consecutivos

    int currentConsecutiveZeros = 0;  // Contador para el número actual de ceros consecutivos
    int currentConsecutiveZerosIndex = -1;  // Índice actual del inicio del tramo de ceros consecutivos

    for (auto i = points.begin(); i != points.end(); ++i) {
        if ((i->second.x() == 0.0 && i->second.y() == 0.0 && i->second.z() == 0.0)) {
            if (currentConsecutiveZeros == 0) {
                currentConsecutiveZerosIndex = std::distance(points.begin(), i);
            }
            currentConsecutiveZeros++;
        } else {
            if (currentConsecutiveZeros > maxConsecutiveZeros) {
                maxConsecutiveZeros = currentConsecutiveZeros;
                maxConsecutiveZerosIndex = currentConsecutiveZerosIndex;
            }
            currentConsecutiveZeros = 0;
        }
    }

    if (currentConsecutiveZeros > maxConsecutiveZeros) {
        // Si la última secuencia de ceros es la más larga
        maxConsecutiveZeros = currentConsecutiveZeros;
        maxConsecutiveZerosIndex = currentConsecutiveZerosIndex;
    }

    // Calculamos el índice del punto del medio
    int middleZeroIndex = maxConsecutiveZerosIndex + maxConsecutiveZeros / 2;

    return middleZeroIndex;
};

auto main() -> int
{
    cam_params.width = 752;
    cam_params.height = 480;
    cam_params.fps = 15;
    cam_params.exposure = 100;
    cam_params.gain = 0;
    cam_params.led = 25;


    Robot robot;
    Vision vision(cam_params);
    I2C i2c("/dev/i2c-1", ARDUINO_ADDRESS);
    Navegacion nav(i2c);
    Map map(0.01);
    MonteCarloLocalization localization(20);


    auto start_time = std::chrono::steady_clock::now();
    auto current_time = std::chrono::steady_clock::now();

    bool object = false;
    bool wall = false;

    doRecognition(&robot, &map, &vision, &nav);

    start_time = std::chrono::steady_clock::now();
    current_time = std::chrono::steady_clock::now();

    while (current_time - start_time < std::chrono::seconds(120))
    {
        wall = i2c.getMinimumUltraSoundValue().second < LIMIT_ULTRASENSOR;
        if (wall && !object)
            wall = i2c.getMinimumUltraSoundValue().second < LIMIT_ULTRASENSOR;


        cv::Mat camera_points = vision.detect_points();
        std::vector<cv::Point3f> cam_points = camera_points;
        std::vector<cv::Point3f> good_points = vision.filter_out_faraway_points(cam_points);
        localization.localize(robot, cam_points, map);
        std::vector<cv::Point3f> points = vision.camera_points_to_world(good_points, robot.compute_own_camera_position(), robot.get_orientation());
        map.InsertPointsInTree(points);
        map.SaveMapToFile("mapa");

        EnvironmentPerception perception = map.ComputeRayCasts(
            robot.get_position(),
            robot.get_orientation()
        );

        std::vector<std::pair<bool, octomap::point3d>> tochamen = perception.get_cylinder();
        std::cout << "Longitud del vector: " << tochamen.size() << std::endl;
        for(auto& pareja : tochamen){
            std::cout <<"Pareja de cylindro: " << pareja.second << std::endl;
	    }
            
        int index = findMiddleZeroIndex(tochamen);
        std::cout << "Index Value: " << index << std::endl;
        float radians = index * (M_PI / 180.0);
        std::cout <<"Radians: " << radians << std::endl;
        std::pair<bool, int> escape = robot.rad_to_pulses(radians);
        std::cout <<"Me muevorrr:" << escape.first << std::endl;
        std::cout <<"Pulses needed:" << escape.second << std::endl;

        int idk = nav.turn_right_pulses(escape.second);
        robot.turn_from_last_known_with_pulses(true, idk);


        robot.commit();
        int pulsos = nav.forward();
        std::cout << "pulsos: " << pulsos << std::endl;
        robot.move_from_last_known(robot.pulses_to_meters(pulsos));
        robot.commit();

        current_time = std::chrono::steady_clock::now();
    }
    map.SaveMapToFile("mapa");
    return 0;
}

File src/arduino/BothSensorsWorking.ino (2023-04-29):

int pin_trigger1 = 9;
int pin_echo1 = 7;

int pin_trigger2 = 2;
int pin_echo2 = 4;

void _setup() {
  // put your setup code here, to run once:
  pinMode(LED_BUILTIN, OUTPUT);//Inicializamos el led incorporado en la propia placa como una salida  
  Serial.begin(9600);
  pinMode(pin_trigger1, OUTPUT);
  pinMode(pin_echo1, INPUT);
  pinMode(pin_trigger2, OUTPUT);
  pinMode(pin_echo2, INPUT);
}

void _loop() {
  digitalWrite(pin_trigger1, LOW);
  digitalWrite(pin_trigger2, LOW); 
  delayMicroseconds(4);
  digitalWrite(pin_trigger1, HIGH);
  digitalWrite(pin_trigger2, HIGH); //generamos Trigger (disparo) de 10us
  
  delayMicroseconds(10);

  digitalWrite(pin_trigger1, LOW);
  long duration1 = pulseIn(pin_echo1, HIGH);
  digitalWrite(pin_trigger2, LOW);
  long duration2 = pulseIn(pin_echo2, HIGH); //medimos el tiempo entre pulsos, en microsegundos
  
  long distanceCm1 = duration1 * 10 / 292/ 2;//convertimos a distancia, en cm
  long distanceCm2 = duration2 * 10 / 292/ 2;
  Serial.print("Distance Sensor 1: ");
  Serial.println(distanceCm1);
  Serial.print("Distance Sensor 2: ");
  Serial.println(distanceCm2);
  delay(1000);
}

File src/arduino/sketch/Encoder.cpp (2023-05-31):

#include "Encoder.h"
#include <Arduino.h>

void Encoder::reset()
{
  updates = 0;
  value = 0;
  correct_value = 0;
  last_encoded = 0;
}

void Encoder::update()
{
  int MSB = digitalRead(pin_a); //MSB = most significant bit
  int LSB = digitalRead(pin_b); //LSB = least significant bit
 
  int encoded = (MSB << 1) | LSB; //converting the 2 pin value to single number
  int sum  = (last_encoded << 2) | encoded; //adding it to the previous encoded value
 
  if(sum == 0b1101 || sum == 0b0100 || sum == 0b0010 || sum == 0b1011) value ++;
  if(sum == 0b1110 || sum == 0b0111 || sum == 0b0001 || sum == 0b1000) value --;
 
  last_encoded = encoded; //store this value for next time
  updates++;
}

int16_t Encoder::read()
{
  return value / 4;
}

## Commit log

2023-04-08 RobotDesign V1
    [ROBOT DESIGN.stl]
2023-04-13 Esquema Fritzing
    [RoboFinder.fzz]
2023-04-20 subido el codigo del arduino
2023-04-26 Test Encoders con nuestro HW
2023-04-26 codigo de los encoders funcionando
2023-04-30 Arduino. UltrasoundSensor.ino -> *.h i *.cpp
2023-04-30 Arduino. Codigo de I2C en pruebas
2023-04-30 I2C tipologia para los mensajes
2023-04-30 Codigo de pruebas para I2C
2023-04-30 Arduino. Recibe parametros por I2C desde la Jetson (Probado con Raspberry)
2023-04-30 Diseño para la fresadora
    [Base Robofinder.dxf, Piso Robofinder.dxf, Soporte Camara Robofinder.dxf]
2023-05-02 Arduino. I2C con valores de 2Bytes.
2023-05-11 el codigo de la jetson empezado en cpp
2023-05-13 Comunicacion i2c nuevos canales. I puertos del arduino igual al esquematico
2023-05-13 Control I2C Motores Arduino
2023-05-13 lectura de las camaras con buen framerate
2023-05-14 I2C. Leer valores de los encoders
2023-05-17 I2C. Sensors ultraso. Canal i2c jetson
2023-05-18 I2C. Codigo en C
2023-05-21 I2C. Nuevos mensajes
2023-05-21 I2C. Control para la Jetson en Python con los dos mensajes posibles de I2C
2023-05-24 cosas de vision que van
2023-05-25 Codigo Arduino. Parada automatica con sensores ultrasonido
2023-05-25 percepcion de profundidad con el estereo
2023-05-27 Arduino. Matrix Led
2023-05-27 Arduino. led.h y led.cpp
2023-05-27 Arduino. limpieza en led.h y led.cpp
2023-05-27 Jetson. Codigo I2C no acabado
2023-05-27 evitar frames rotos
2023-05-29 I2C Jetson. Clase de I2C para la Jetson
2023-05-29 Soporte 3D para la matriz led
    [32x8_matrix_v09.stl, 32x8_matrix_v09_mod.stl]
2023-05-29 Update Tipologia mensajes I2C.docx
2023-05-29 Modelo Ventilador
    [fan.stl, fan_base.stl]
2023-05-29 I2C por probar Arnau no me mates
2023-05-29 i2c no va
2023-05-30 i2c funcionando
2023-05-31 encoders funcionando
2023-05-31 Robot.cpp añadida las funciones de conversion
2023-05-31 puto windows de mierda
2023-05-31 :) arnau ha arreglado la camara :)
    [Vision.h, main.cpp]
2023-05-31 ARNAU: robot actualiza la posicion
2023-05-31 arreglado i2c
2023-06-01 I2C arduino
2023-06-01 Encoders rectified
2023-06-01 Modelos 3D STL
    [Base Robofinder.stl, Piso Robofinder.stl, Soporte Camara Robofinder.stl]
2023-06-01 Jetson. Codigo de navegacion inicial
2023-06-01 Jetson. Navegacion empezamos a marcar la posicion. Esta por acabar
2023-06-03 Create Imagenes para readme
2023-06-03 I2C. Ultrasonido
2023-06-03 Jetson. Raycast
2023-06-03 correccion eje coordendas de opencv a octomap
2023-06-03 Metodo para exposicion automatica (testing)
2023-06-03 que la camara no sea el 0 0 0
2023-06-03 percepcion en el mapa con raycast
2023-06-03 corregido error de lectura del encoder derecho y hermosa vista
    [I2C.cpp, main.cpp, navegacion.cpp]
2023-06-03 Prototype MonteCarlo
2023-06-04 preparando codigo para la localización
2023-06-04 Imagenes para el Readme
2023-06-04 Diseños 3d del robot
    [Piezas_robofinder_montado.3mf, Piezas_robofinder_montado.stl, soporte_ultrasonido.stl]
2023-06-05 arreglado que los puntos de la camara virtual sean unicos y que las de la camara salgan en el espacio correcto z arriba
2023-06-05 Readme. Imágenes que no se usan borradas
2023-06-05 ultima version que tenemos
